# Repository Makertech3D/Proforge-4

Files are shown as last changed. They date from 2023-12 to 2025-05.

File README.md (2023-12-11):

# Proforge-4 High Speed Tool Changing 3D Printer
Official repo for the Proforge 4 Toolchanger 3D printer

Proforge 4 Render

The Proforge 4 Tool Changer 3D printer draws inspiration from the E3D Tool Changer, Voron 3D printer, and VZ Bot 3D printer. It enables high-speed multi-material 3D printing and operates as an open-source machine utilizing Klipper firmware, BigtreeTech control boards, and LDO motors. Crafted with precision CNC'd components, linear rails, and Gates belts, it aims for top-notch quality.

With an ample build volume of 400x300x400mm (X, Y, and Z respectively), the Proforge 4 offers versatility. It can also be enclosed for printing ABS filament. Our custom-designed hotend ensures high flow and speed. Impressively, a 3D Benchy in ABS with good quality can be printed in just around 13 minutes at maximum speed.

# Proforge 4 Build Manual

The Official build guides for the Proforge 4 3D printer can be found [here](https://makertech-3d.dozuki.com/c/Proforge_4)

The BOM (Bill of Materials) can be found [here](https://docs.google.com/spreadsheets/d/1Y5VUGZzWMNDWVGi7vUqABhzv31rmcmznpvWCIOyDUW4/edit?usp=sharing).

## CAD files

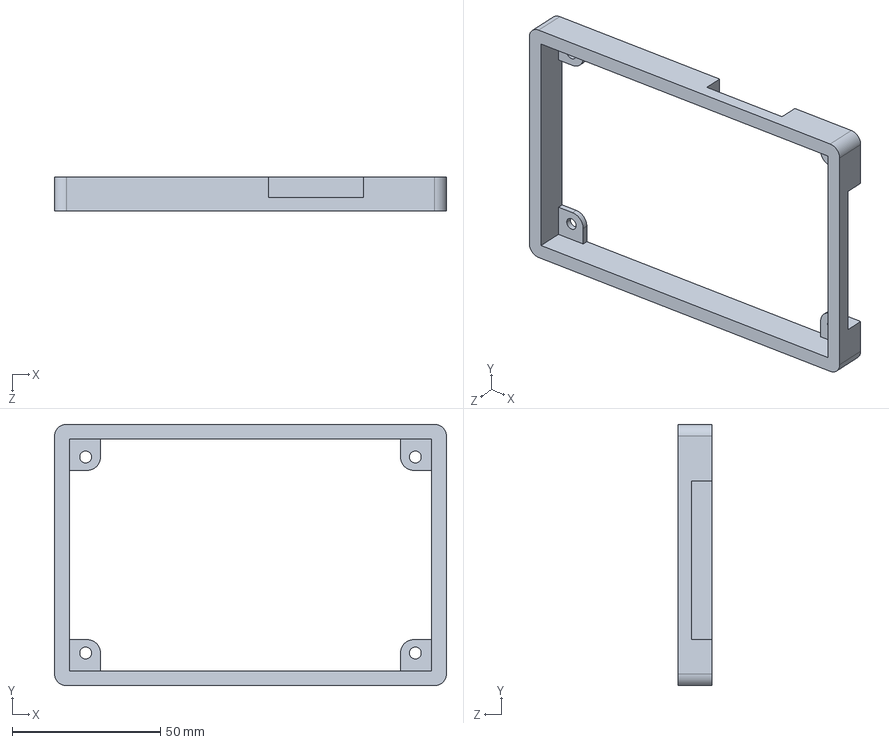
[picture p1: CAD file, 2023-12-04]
3D Printed Parts/P4_3D Printed Screen Case.STEP
132.0 x 88.0 x 11.5 mm

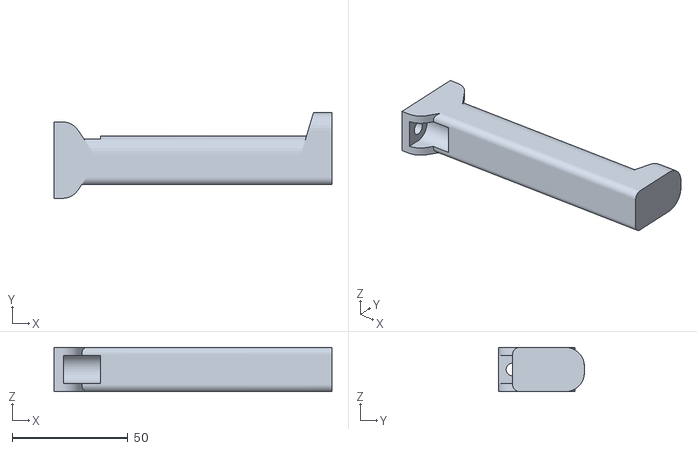
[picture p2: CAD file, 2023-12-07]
P4_3D Printed Spool Holder.STL
120.0 x 37.0 x 19.0

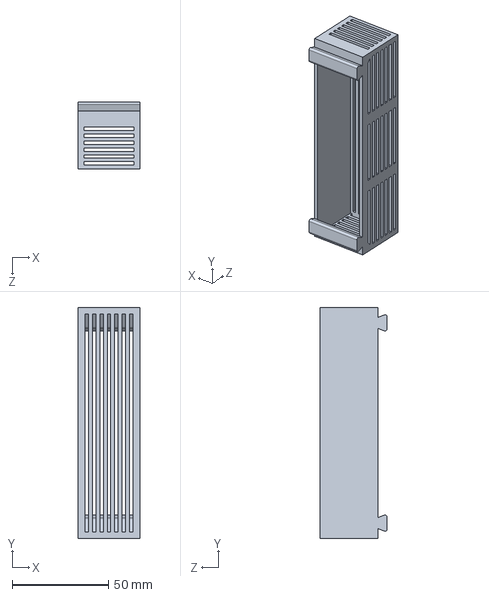
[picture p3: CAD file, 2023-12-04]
3D Printed Parts/P4_3D Printed Fume Filter - Pellet Tray.STEP
32.0 x 120.0 x 34.8 mm

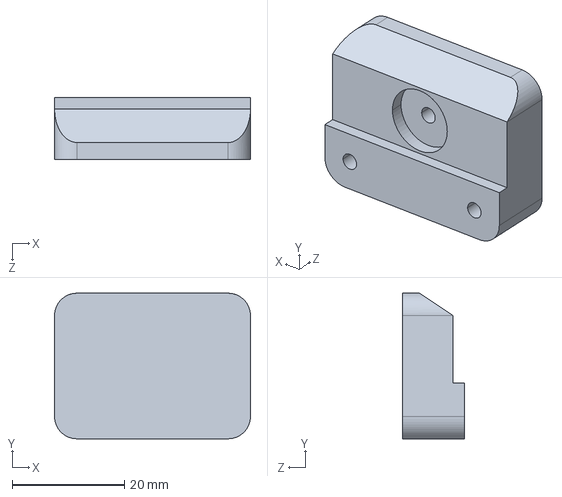
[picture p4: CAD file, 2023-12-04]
3D Printed Parts/P4_3D Printed Enclosure Door Handle.STEP
35.0 x 26.0 x 11.0 mm

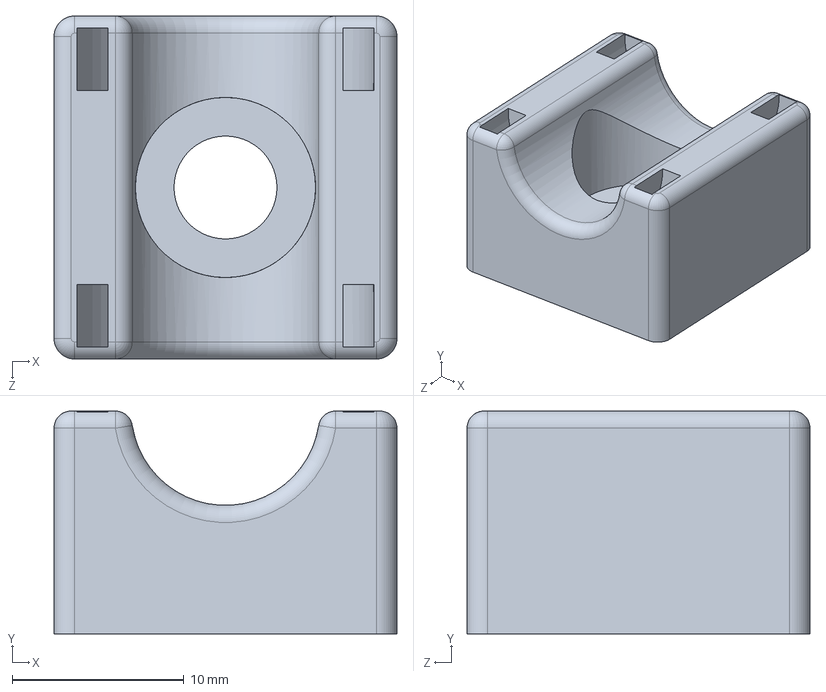
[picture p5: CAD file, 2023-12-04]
3D Printed Parts/P4_3D Printed Cable Guide.STEP
20.0 x 13.0 x 20.0 mm

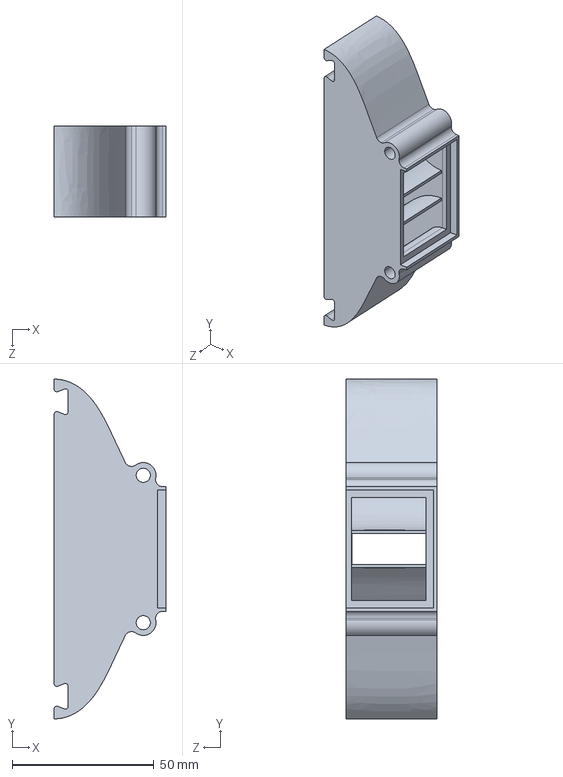
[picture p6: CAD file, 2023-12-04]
3D Printed Parts/P4_3D Printed Fume Filter - Fan Shroud.STEP
39.5 x 120.0 x 32.0 mm

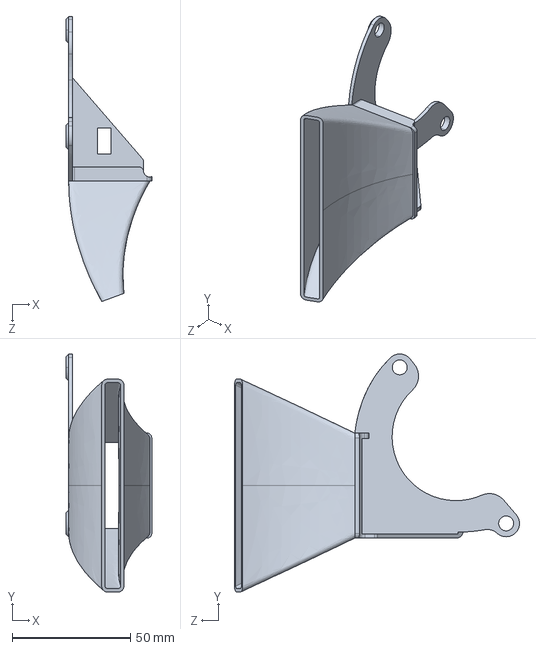
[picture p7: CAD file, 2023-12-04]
3D Printed Parts/P4_3D Printed Static Cooling Fan Shroud.STEP
36.2 x 100.6 x 120.5 mm

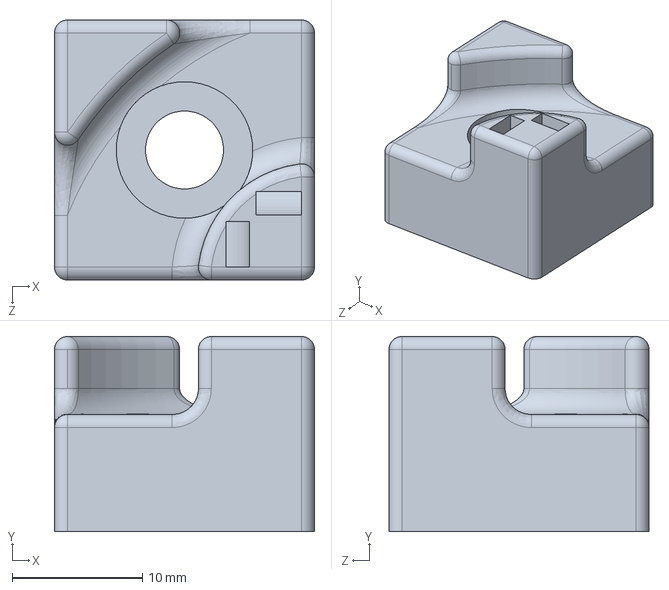
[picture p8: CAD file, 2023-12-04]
3D Printed Parts/P4_3D Printed Cable Guide - Right Angle.STEP
20.0 x 15.0 x 20.0 mm

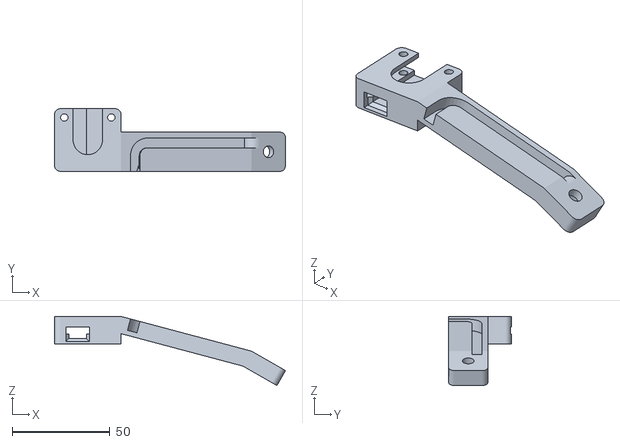
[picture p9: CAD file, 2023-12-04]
3D Printed Parts/P4_3D Printed Cam Case.STL
118.0 x 32.0 x 35.3

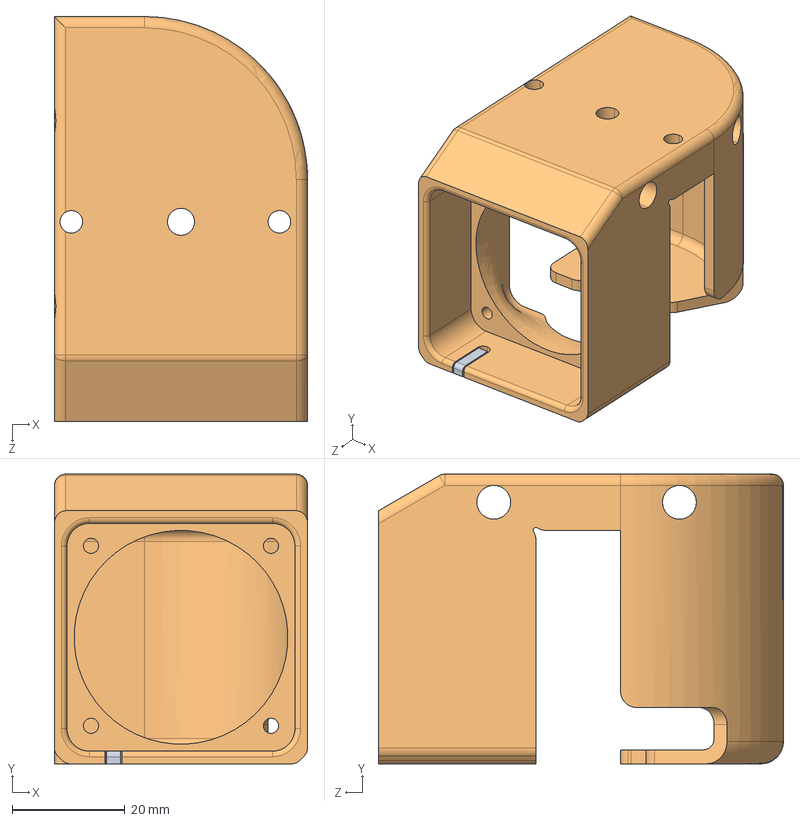
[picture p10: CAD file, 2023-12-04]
3D Printed Parts/P4_3D Printed Hotend Case.STEP
45.0 x 51.5 x 72.0 mm

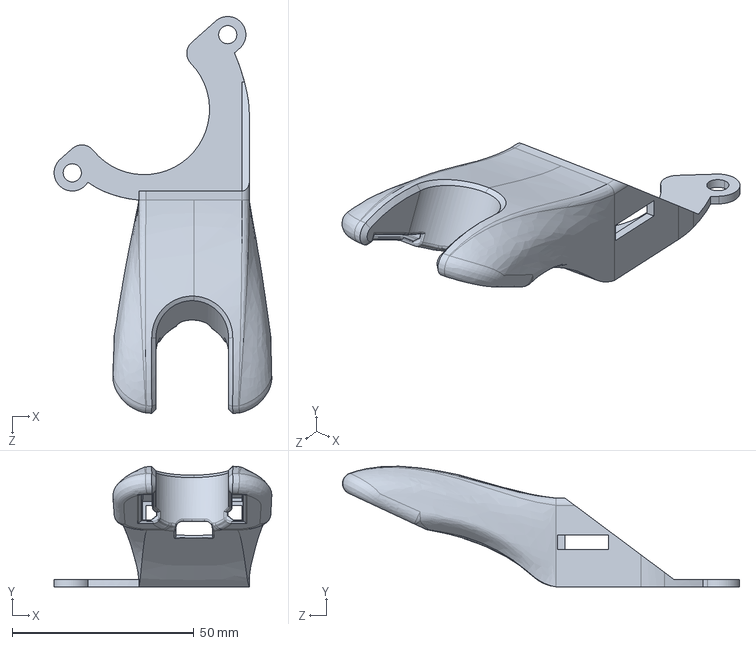
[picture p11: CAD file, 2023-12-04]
3D Printed Parts/P4_3D Printed Part Coolling Fan Shroud.STEP
59.9 x 33.2 x 109.2 mm

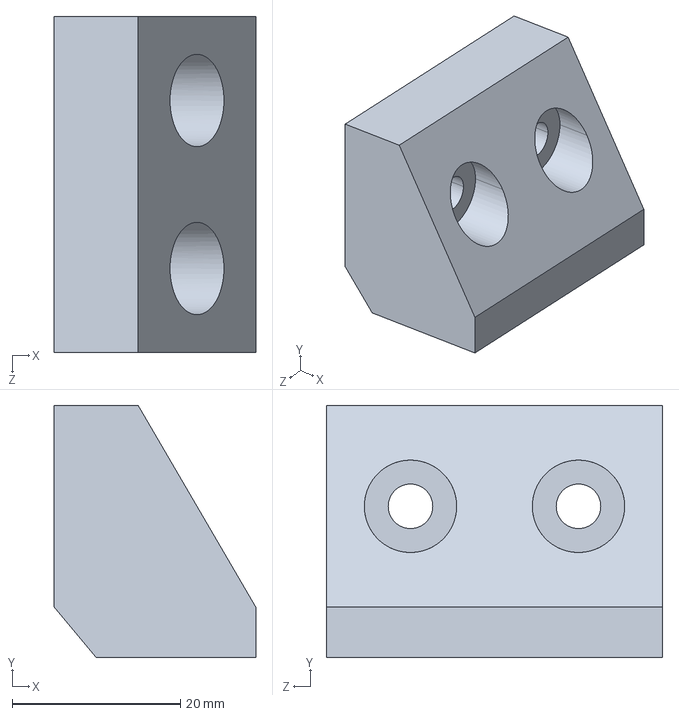
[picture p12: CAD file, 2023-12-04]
3D Printed Parts/P4_3D Printed Enclosure Roof Stopper.STEP
24.0 x 30.0 x 40.0 mm

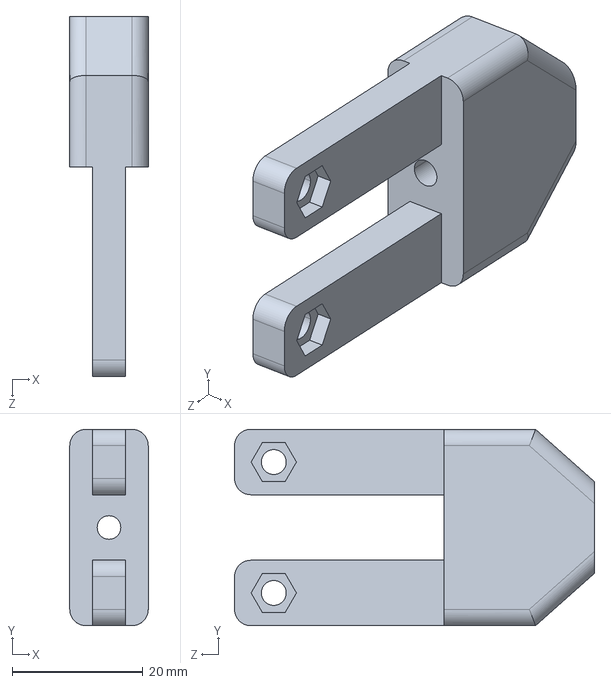
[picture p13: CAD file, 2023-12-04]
3D Printed Parts/P3_3D Printed Dock Bracket.STEP
12.0 x 30.0 x 55.0 mm

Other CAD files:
3D Printed Parts/P3_3D Printed Dock Bracket.STL
3D Printed Parts/P4_3D Printed Cable Guide - Right Angle.STL
3D Printed Parts/P4_3D Printed Cable Guide.STL
3D Printed Parts/P4_3D Printed Enclosure Door Handle.STL
3D Printed Parts/P4_3D Printed Enclosure Roof Stopper.STL
3D Printed Parts/P4_3D Printed Fume Filter - Fan Shroud.STL
3D Printed Parts/P4_3D Printed Fume Filter - Pellet Tray.STL
3D Printed Parts/P4_3D Printed Hotend Case.STL
3D Printed Parts/P4_3D Printed Part Coolling Fan Shroud.STL
3D Printed Parts/P4_3D Printed Screen Case.STL
3D Printed Parts/P4_3D Printed Static Cooling Fan Shroud.STL

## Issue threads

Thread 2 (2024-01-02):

z_tilt configuration flawed

thereseLYR, 2024-01-02:
Link to current state of printer.cfg for reference: [HERE](https://github.com/Makertech3D/Proforge-4/blob/047a191c89f301492370d93dd41504570838a8a2/Proforge%204%20Firmware%20Files/printer.cfg)

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
Currently, the config file is not implementing z-tilt in a useful way for the following reasons:
- `retries: 0`,means that the printer takes ONE set of readings and stops probing/adjusting, instead of re-running the
- `retry_tolerance: 0.2` means that the printbed tilt tilt can be off by ONE ENTIRE LAYER across the bed and still report as 'fine'. This is a huge amount of tolerance that may cause first layer issues on larger prints, or prints farther away from the center of the bed.

Suggested fix:
- Increase retries + decrease tolerance
- refer to the Voron Trident (tri-bed-levelled printer)'s [config](https://github.com/VoronDesign/Voron-Trident/blob/main/Firmware/Octopus/Trident_Octopus_Config.cfg) as a reference for well-implemented z-tilt:
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

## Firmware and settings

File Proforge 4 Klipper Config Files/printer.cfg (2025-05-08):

# This printer config file is configured for the Proforge 4 Tool Changer 3D printer. 
# It is intended to be run with the BigTreeTech Octopus Max EZ control board.

# Release version 1.0.7
# Change log:
# V1.0.7:
# - Auto Calibration Probe include line
# V1.0.6:
# - min_extrude_temp set to 150 for all hotends.
# V1.0.5:
# - relative_reference_index in bed_mesh deprecated
# V1.0.4:
# - Orbiter Filament Sensor
# V1.0.3:
# - Input Shaper S2DW 
# V1.0.2:
# - Z-motor directions corrected
# - Max Z heihht corrected to 400
# V1.0.1:
# - Filament sensor logic for T0 corrected
# - Pull up resistor value added for PT1000 probe on T1, T2 and T3 to fix temp errors.


[include mainsail.cfg]
[include macros.cfg]
[include calibrate-offsets.cfg]
#[include OrbiterSensor0.cfg]
#[include OrbiterSensor1.cfg]
#[include OrbiterSensor2.cfg]
#[include OrbiterSensor3.cfg]
#[include S2DW.cfg]
[save_variables]
filename: ~/printer_data/config/variables.cfg
#   Required - provide a filename that would be used to save the
#   variables to disk e.g. ~/variables.cfg
[virtual_sdcard]
path: ~/printer_data/gcodes

[mcu]
serial: 

#[mcu rpi]
#serial: /tmp/klipper_host_mcu

[printer]
kinematics: corexy
max_velocity: 800
max_accel: 60000
max_z_velocity: 10
max_z_accel: 100
square_corner_velocity: 20.0


# MOTOR-1
[stepper_x]
step_pin: PC13
dir_pin: PC14
enable_pin: !PE6
rotation_distance:40
microsteps:16
full_steps_per_rotation: 200
#gear_ratio:
#step_pulse_duration:
endstop_pin: PF0
position_min: -100
position_endstop: 400
position_max:400
homing_speed: 80
[tmc5160 stepper_x]
cs_pin: PG14
#   The pin corresponding to the TMC5160 chip select line. This pin
#   will be set to low at the start of SPI messages and raised to high
#   after the message completes. This parameter must be provided.
spi_speed: 2000000
#spi_bus:
spi_software_sclk_pin: PE12
spi_software_mosi_pin: PE14
spi_software_miso_pin: PE13
#   See the "common SPI settings" section for a description of the
#   above parameters.
#chain_position:
#chain_length:
#   These parameters configure an SPI daisy chain. The two parameters
#   define the stepper position in the chain and the total chain length.
#   Position 1 corresponds to the stepper that connects to the MOSI signal.
#   The default is to not use an SPI daisy chain.
interpolate: False
#   If true, enable step interpolation (the driver will internally
#   step at a rate of 256 micro-steps). The default is True.
run_current: 1.4
#   The amount of current (in amps RMS) to configure the driver to use
#   during stepper movement. This parameter must be provided.
#hold_current:
#   The amount of current (in amps RMS) to configure the driver to use
#   when the stepper is not moving. Setting a hold_current is not
#   recommended (see TMC_Drivers.md for details). The default is to
#   not reduce the current.
sense_resistor: 0.05
#   The resistance (in ohms) of the motor sense resistor. The default
#   is 0.075 ohms.
stealthchop_threshold: 0
driver_TBL: 0
driver_TOFF: 1
#   The velocity (in mm/s) to set the "stealthChop" threshold to. When
#   set, "stealthChop" mode will be enabled if the stepper motor
#   velocity is below this value. The default is 0, which disables
#   "stealthChop" mode.
#driver_MSLUT0: 2863314260
#driver_MSLUT1: 1251300522
#driver_MSLUT2: 608774441
#driver_MSLUT3: 269500962
#driver_MSLUT4: 4227858431
#driver_MSLUT5: 3048961917
#driver_MSLUT6: 1227445590
#driver_MSLUT7: 4211234
#driver_W0: 2
#driver_W1: 1
#driver_W2: 1
#driver_W3: 1
#driver_X1: 128
#driver_X2: 255
#driver_X3: 255
#driver_START_SIN: 0
#driver_START_SIN90: 247
#   These fields control the Microstep Table registers directly. The optimal
#   wave table is specific to each motor and might vary with current. An
#   optimal configuration will have minimal print artifacts caused by
#   non-linear stepper movement. The values specified above are the default
#   values used by the driver. The value must be specified as a decimal integer
#   (hex form is not supported). In order to compute the wave table fields,
#   see the tmc2130 "Calculation Sheet" from the Trinamic website.
#driver_IHOLDDELAY: 6
#driver_TPOWERDOWN: 10
#driver_TBL: 2
#driver_TOFF: 3
#driver_HEND: 2
#driver_HSTRT: 5
#driver_FD3: 0
#driver_TPFD: 4
#driver_CHM: 0
#driver_VHIGHFS: 0
#driver_VHIGHCHM: 0
#driver_DISS2G: 0
#driver_DISS2VS: 0
#driver_PWM_AUTOSCALE: True
#driver_PWM_AUTOGRAD: True
#driver_PWM_FREQ: 0
#driver_FREEWHEEL: 0
#driver_PWM_GRAD: 0
#driver_PWM_OFS: 30
#driver_PWM_REG: 4
#driver_PWM_LIM: 12
#driver_SGT: 0
#driver_SEMIN: 0
#driver_SEUP: 0
#driver_SEMAX: 0
#driver_SEDN: 0
#driver_SEIMIN: 0
#driver_SFILT: 0
#   Set the given register during the configuration of the TMC5160
#   chip. This may be used to set custom motor parameters. The
#   defaults for each parameter are next to the parameter name in the
#   above list.
#diag0_pin:
#diag1_pin:
#   The micro-controller pin attached to one of the DIAG lines of the
#   TMC5160 chip. Only a single diag pin should be specified. The pin
#   is "active low" and is thus normally prefaced with "^!". Setting
#   this creates a "tmc5160_stepper_x:virtual_endstop" virtual pin
#   which may be used as the stepper's endstop_pin. Doing this enables
#   "sensorless homing". (Be sure to also set driver_SGT to an
#   appropriate sensitivity value.) The default is to not enable
#   sensorless homing.



# MOTOR-2
[stepper_y]
step_pin: PE4
dir_pin: !PE5
enable_pin: !PE3
rotation_distance:40
microsteps:16
full_steps_per_rotation: 200
#gear_ratio:
#step_pulse_duration:
endstop_pin: PF2
position_min: 0
position_endstop: 0
position_max:300
homing_speed: 80
[tmc5160 stepper_y]
cs_pin: PG13
#   The pin corresponding to the TMC5160 chip select line. This pin
#   will be set to low at the start of SPI messages and raised to high
#   after the message completes. This parameter must be provided.
spi_speed: 2000000
#spi_bus:
spi_software_sclk_pin: PE12
spi_software_mosi_pin: PE14
spi_software_miso_pin: PE13
#   See the "common SPI settings" section for a description of the
#   above parameters.
#chain_position:
#chain_length:
#   These parameters configure an SPI daisy chain. The two parameters
#   define the stepper position in the chain and the total chain length.
#   Position 1 corresponds to the stepper that connects to the MOSI signal.
#   The default is to not use an SPI daisy chain.
interpolate: False
#   If true, enable step interpolation (the driver will internally
#   step at a rate of 256 micro-steps). The default is True.
run_current: 1.4
#   The amount of current (in amps RMS) to configure the driver to use
#   during stepper movement. This parameter must be provided.
#hold_current:
#   The amount of current (in amps RMS) to configure the driver to use
#   when the stepper is not moving. Setting a hold_current is not
#   recommended (see TMC_Drivers.md for details). The default is to
#   not reduce the current.
sense_resistor: 0.05
#   The resistance (in ohms) of the motor sense resistor. The default
#   is 0.075 ohms.
stealthchop_threshold: 0
driver_TBL: 0
driver_TOFF: 1
#   The velocity (in mm/s) to set the "stealthChop" threshold to. When
#   set, "stealthChop" mode will be enabled if the stepper motor
#   velocity is below this value. The default is 0, which disables
#   "stealthChop" mode.
#driver_MSLUT0: 2863314260
#driver_MSLUT1: 1251300522
#driver_MSLUT2: 608774441
#driver_MSLUT3: 269500962
#driver_MSLUT4: 4227858431
#driver_MSLUT5: 3048961917
#driver_MSLUT6: 1227445590
#driver_MSLUT7: 4211234
#driver_W0: 2
#driver_W1: 1
#driver_W2: 1
#driver_W3: 1
#driver_X1: 128
#driver_X2: 255
#driver_X3: 255
#driver_START_SIN: 0
#driver_START_SIN90: 247
#   These fields control the Microstep Table registers directly. The optimal
#   wave table is specific to each motor and might vary with current. An
#   optimal configuration will have minimal print artifacts caused by
#   non-linear stepper movement. The values specified above are the default
#   values used by the driver. The value must be specified as a decimal integer
#   (hex form is not supported). In order to compute the wave table fields,
#   see the tmc2130 "Calculation Sheet" from the Trinamic website.
#driver_IHOLDDELAY: 6
#driver_TPOWERDOWN: 10
#driver_TBL: 2
#driver_TOFF: 3
#driver_HEND: 2
#driver_HSTRT: 5
#driver_FD3: 0
#driver_TPFD: 4
#driver_CHM: 0
#driver_VHIGHFS: 0
#driver_VHIGHCHM: 0
#driver_DISS2G: 0
#driver_DISS2VS: 0
#driver_PWM_AUTOSCALE: True
#driver_PWM_AUTOGRAD: True
#driver_PWM_FREQ: 0
#driver_FREEWHEEL: 0
#driver_PWM_GRAD: 0
#driver_PWM_OFS: 30
#driver_PWM_REG: 4
#driver_PWM_LIM: 12
#driver_SGT: 0
#driver_SEMIN: 0
#driver_SEUP: 0
#driver_SEMAX: 0
#driver_SEDN: 0
#driver_SEIMIN: 0
#driver_SFILT: 0
#   Set the given register during the configuration of the TMC5160
#   chip. This may be used to set custom motor parameters. The
#   defaults for each parameter are next to the parameter name in the
#   above list.
#diag0_pin:
#diag1_pin:
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

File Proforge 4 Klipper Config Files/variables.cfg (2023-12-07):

# This variables config file is configured for the Proforge 4 Tool Changer 3D printer. 
# It is intended to be run witht the BigTreeTech Octopus Max EZ control board.

# Release version 1.0.0



[Variables]

# Tool Head Select/Dock Positions:

# Tool Head 0:
zero_x = -70
zero_y = 14.0

# Tool Head 1:
one_x = -70
one_y = 108

# Tool Head 2:
two_x = -70
two_y = 201

# Tool Head 3:
three_x = -70
three_y = 296



# Tool Head Z Offsets:

one_z_offset = 0
two_z_offset = 0
three_z_offset = 0




# Tool Head X/Y Offsets:

# Tool Head 0: 
# (0,0,0) by default

# Tool Head 1 Offset:
one_x_offset = 0
one_y_offset = 0

# Tool Head 2 Offset:
two_x_offset = 0
two_y_offset = 0

# Tool Head 3 Offset:
three_x_offset = 0
three_y_offset = 0

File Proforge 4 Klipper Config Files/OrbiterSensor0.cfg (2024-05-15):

#################################################################################################################
################################# Orbiter Sensor 0 CONFIGURATION ################################################
#################################################################################################################

#config file version v2.2.04
#release date: 23.09.2023

# PAUSE and RESUME macros are defined at the end of this config file.
# If you prefer using your own p[lease delete them, otherwise define parking position below.

#################################################################################################################
################################# CHANGE HERE MACRO CONFIGURABLES################################################
#################################################################################################################

[gcode_macro _SENSOR_VARIABLES]         # change here macro configurables, enable disable functions!*************************
variable_filament_load_temp     :200    # temperature to heat up hotend for filament loading, default is 235
variable_filament_unload_temp   :185    # temperature to heat up hotend for filament un-loading, default is 185
variable_filament_load_min_temp :190    # minimum hotend set temperature allowed in filament load macro, default is 190
variable_nozzle_purge_length    :100    # filament extrude amount during load sequenc, hotend purge from old filament, default is 200
variable_nozzle_purge_speed     :450    # filament extrude speed in mm/min adjust this value lower if flow is too high and extruder skips during loading, default is 300
variable_unload_distance        :130     # filament retract distance for unload procedure. this length shall be long enough to extract the filament above the drive gears
variable_disable_autoload       :False  # disable filament autoload feature by setting this variable True
variable_disable_runnout        :False  # disable runnout by setting this variable True
variable_disable_autounload     :False  # disable auto unload filament by setting this variable to True
variable_enable_beep            :False   # uses M300 sound feature, set it True to enable
variable_park_position_x        :10    # edit your X parking position here for pause macro trigerred by runnout
variable_park_position_y        :10     # edit your Y parking position here for pause macro trigerred by runnout
variable_park_lift_z            :10     # edit your Z lift amount for parking position here, default is 10
Variable_park_retraction        :1      # edit your retraction amount for parking, default is 1
gcode:

#///////////////////////////filament sensor button macros/////////////////////////////////////////////////
[gcode_button filament_sense]
pin: !PF4 # remove the negation "!" for sensor v1 - use just PA9 as example
press_gcode: # sensor released  -runnout detected!
  {% if printer.toolhead.extruder == "extruder" %}
  _runnout_init
  {% else %}
  {% endif %}

release_gcode: #gcode macro for filament auto-load, sensor pressed
  {% if printer.toolhead.extruder == "extruder" %}
  _filament_load_init
  {% else %}
  {% endif %}
#********************************************************************************************************

#////////////////////////////////////////Filament Unload macros/////////////////////////////////////////////////
[gcode_button filament_unload]
pin: !PD9 # remove the negation "!" for sensor v1 - use just PA9 as example
release_gcode:  # filament unload procedure   
  {% if printer.toolhead.extruder == "extruder" %}
  _filament_unload_init
  {% else %}
  {% endif %}
press_gcode: # do not add any macro call here

#################################################################################################################################
####################################### DO NOT CHANGE ANYTHING BELOW THIS LINE!!! ###############################################
#################################################################################################################################


[respond]
default_type: echo

[force_move]
enable_force_move: True

####################################### Runout and Auto-Unload Code ###############################################

[gcode_macro _runnout_init] 
gcode:
  {% set sensor = printer['gcode_macro _SENSOR_VARIABLES'] %}  
  {% if (printer.print_stats.state == "printing") %}      
    {% if(sensor.disable_runnout|lower == 'false') %}
    _filament_change_state_a
   {% else %}
    M118 Filament runnout is disabled in the sensor config file!   
    {% endif %}     
  {% endif %} 
  UPDATE_DELAYED_GCODE ID=clear_loadbusy DURATION=2
  UPDATE_DELAYED_GCODE ID=clear_unloadbusy DURATION=2    
  SET_GCODE_VARIABLE MACRO=_filament_unload VARIABLE=filamentpresent VALUE=0



[gcode_macro _filament_change_state_a]
variable_changebusy: 0
variable_temp_target: 0
gcode:
  {% set sensor = printer['gcode_macro _SENSOR_VARIABLES'] %}  
  {% if changebusy == 0 %}
    PAUSE # call printer pause macro      
    SET_GCODE_VARIABLE MACRO=_filament_change_state_a VARIABLE=changebusy VALUE=1       
    M118 Filament runnout on print head 0!       
    _filament_change_state_b     # comment this line if you do not want to automatically unload filament in case there is a runnout detected.
  {% else %}
  {% endif %}

[gcode_macro _filament_change_state_b]
gcode:
  {% set sensor = printer['gcode_macro _SENSOR_VARIABLES'] %}  
  SET_GCODE_VARIABLE MACRO=_filament_load VARIABLE=loadbusy VALUE=1      
  {% if (sensor.enable_beep|lower == 'true') %} 
    M300 # beep sound
  {% endif %}
  M118 Unloading filament on print head 0...   
  M83
  G92 E0   
  # {% if printer[printer.toolhead.extruder].temperature < 185 %} # hardcoded threshold
  {% if (printer.extruder.can_extrude|lower != 'true')%} # checking for minimum extrusion temperature
        # check if temperature is over the minimum extrusion temp. min_extrude_temp must be defined in the extruder config (to about 185)
      M118 Hotend 0 heating!        
      SET_HEATER_TEMPERATURE HEATER=extruder TARGET={sensor.filament_unload_temp} # restore user temp if it was set before loading
      TEMPERATURE_WAIT SENSOR=extruder MINIMUM={sensor.filament_unload_temp} #wait for reaching filament unload temp
      {% endif %}     
  {% if(printer.extruder.target == 0) %} # checking for set temperature if is zero than set to 200 / hotend hot but cooling due to set target temp 0
      SET_HEATER_TEMPERATURE HEATER=extruder TARGET={sensor.filament_unload_temp} # restore user temp if it was set before loading
      TEMPERATURE_WAIT SENSOR=extruder MINIMUM={sensor.filament_unload_temp} #wait for reaching filament unload temp
  {% endif %} 
  G0 E-5 F3600  #extract filament to cold end
  G4 P2000 # wait for two seconds
  G0 E5 F3600 # push the filament back 
  G0 E-5 F3600  #extract filament to cold end
  G0 E-{sensor.unload_distance} F300  # continue extraction slow allow filament to be cooled enough before reaches the gears  
  M400   
  M118 Load new filament! Wait until is loaded, then resume printing.  
  #SET_HEATER_TEMPERATURE HEATER=extruder TARGET=0 # swicth off heater
  UPDATE_DELAYED_GCODE ID=clear_loadbusy DURATION=2.5 # timing must be set to clear delay plus 0.5s. is due to wait to remove filament before starting load even in case there is a blob at the tip of the extracted filament which woudl trigger the sensor twice




####################################### Filament Loading Code ###############################################


[gcode_macro _filament_load_init]
gcode:
  {% set sensor = printer['gcode_macro _SENSOR_VARIABLES'] %}
  {% if (printer.print_stats.state != "printing") %}
    {% if(sensor.disable_autoload|lower == 'false') %}
      _filament_load
    {% else %}
    M118 Filament auto-load is disabled in the sensor config file!   
    {% endif %} 
  {% else %}    
    M118 Printing! Cannot load filament!  
  {% endif %}
  SET_GCODE_VARIABLE MACRO=_filament_unload VARIABLE=filamentpresent VALUE=1
  UPDATE_DELAYED_GCODE ID=clear_changebusy DURATION=2
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

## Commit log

2023-11-29 Create Proforge 4 BOM.xlsx
    [Proforge 4 BOM.xlsx]
2023-11-29 Proforge 4 BOM
    [Proforge 4 BOM.xlsx, Proforge 4 Public BOM.xlsx]
2023-12-04 3D Printed Parts for the Proforge 4
    [P3_3D Printed Dock Bracket.STEP, P3_3D Printed Dock Bracket.STL, P4_3D Printed Cable Guide - Right Angle.STEP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]
2023-12-07 Firmware cfg files - v1.0.0
    [macros.cfg, printer.cfg, variables.cfg]
2023-12-07 3D Printed Spool Holder
    [P4_3D Printed Spool Holder.STL]
2023-12-11 Google sheets BOM
    https://docs.google.com/spreadsheets/d/1Y5VUGZzWMNDWVGi7vUqABhzv31rmcmznpvWCIOyDUW4/edit?usp=sharing
    [Proforge 4 Public BOM.xlsx]
2023-12-11 Update printer.cfg v1.0.1
    [printer.cfg]
2023-12-12 V1.0.2 printer.cfg
    [printer.cfg]
2024-01-27 config files update
    [macros.cfg, printer.cfg, variables.cfg]
2024-01-31 Input shaper
    [S2DW.cfg, printer.cfg]
2024-01-31 Version notes
    [printer.cfg]
2024-02-11 Orbiter Filament Sensors
    Auto-load and push button unload
    [OrbiterSensor0.cfg, OrbiterSensor1.cfg, OrbiterSensor2.cfg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]
2024-02-26 V1.0.5
    relative_reference_index in bed_mesh deprecated
    [printer.cfg]
2024-03-12 OFS Sensor Pin Correction
    [OrbiterSensor2.cfg, OrbiterSensor3.cfg]
2024-04-15 Min extrude temp set to 150
    [printer.cfg]
2024-05-15 Orbiter Sensor Code Update
    [OrbiterSensor0.cfg, OrbiterSensor1.cfg, OrbiterSensor2.cfg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]
2024-05-20 Update for auto-probe calibration
    [macros.cfg, printer.cfg]
2024-05-20 Calibration Probe Klipper
2024-05-20 Tool Calibration Macros
    [calibrate-offsets.cfg]
2024-05-21 Probe Position Updated
    [calibrate-offsets.cfg]
2024-07-01 Auto-Save Offsets
    Auto-save nozzle offsets
2024-07-31 max_accel_to_decel setting removed
    max_accel_to_decel setting removed
    [printer.cfg]
2025-05-08 Config + Slicer updates
    [macros.cfg, printer.cfg]
